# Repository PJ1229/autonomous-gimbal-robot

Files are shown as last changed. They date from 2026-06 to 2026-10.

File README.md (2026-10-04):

# auto-gimbal
project by PJ Kim

## to-do:
- [ ] order parts
- [ ] set up ros2 on raspi

## dev rules:
1. no ai agents in this repo (ai for research & planning only)
2. this repo is the source of truth for the entire project

## external links
- [devlog](docs/devlog.md)
- [part list](hardware/bom/part-list.md)
- [chassis dimensions](hardware/bom/chassis-dimensions.md)
- [base layout (rough CAD)](hardware/cad/base-layout.md)

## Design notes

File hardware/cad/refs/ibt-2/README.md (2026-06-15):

# IBT-2 (BTS7960) motor driver reference model

High-power H-bridge driver (ordered ×3). Exported for electronics bay layout in Inventor.

| File | Format | Notes |
|---|---|---|
| `ibt-2.step` | STEP | **Module only** — use for chassis footprint (50×50×43 mm) |
| `ibt-2-wiring.step` | STEP | Module + signal wiring + mounting screws |

Board dims: 50 × 50 × 43 mm · ~66 g · 6–27 V · one per drive motor.

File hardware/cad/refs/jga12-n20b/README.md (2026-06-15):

# JGA12-N20B encoder motor reference model

Magnetic encoder N20 gear motor (12 V, ordered ×4). Exported for motor mount layout in Inventor.

| File | Format | Notes |
|---|---|---|
| `jga12-n20b.sat` | ACIS SAT | **Preferred for Inventor** — solid B-rep import |
| `jga12-n20b.stl` | STL | Mesh fallback / quick preview |

Dimensional drawing: [`part-photos/drive/motor.jpeg`](../../bom/part-photos/drive/motor.jpeg)

Key dims: 40 mm overall length, φ3 mm D-shaft, face 12×10 mm, bracket tabs 17.6 mm apart.

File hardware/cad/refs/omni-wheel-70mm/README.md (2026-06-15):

# 70 mm omni wheel reference model

MiJunHD 70 mm omni wheel with coupling (ordered ×3). For wheel clearance and axle layout in Inventor.

## Inventor import

| File | Inventor? | Use |
|---|---|-----|
| `omni-wheel-70mm.step` | **Yes** (best) | Export from `Omni_4_70.SLDASM` → full solid assembly |
| `omni-wheel-70mm-carrier.stl` | Yes (mesh) | Hub/carrier only — rough clearance check |
| `omni-wheel-70mm-roller.stl` | Yes (mesh) | Single roller — place 4× manually if needed |
| `Omni_4_70.SLDASM` | **No** | SolidWorks only — edit source, then export STEP |
| `*.SLDPRT` | **No** | SolidWorks only (gitignored) |

**Recommended workflow**
1. Open `Omni_4_70.SLDASM` in SolidWorks
2. **File → Save As → STEP** → save as `omni-wheel-70mm.step` in this folder
3. In Inventor: open `base.ipt` → **Place Component** → select `omni-wheel-70mm.step`

STL imports are triangle meshes — no precise mates. Use only until STEP is exported.

## Specs

**Dims:** φ70 × 35.4 mm wide · **3 mm** coupling bore · see [`part-photos/drive/omni-wheel.jpg`](../../bom/part-photos/drive/omni-wheel.jpg)

SolidWorks source files stay local (gitignored). Commit `omni-wheel-70mm.step` once exported.

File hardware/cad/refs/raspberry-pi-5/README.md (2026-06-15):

# Raspberry Pi 5 reference models

Exported for chassis layout in Inventor.

| File | Format | Notes |
|---|---|---|
| `raspberry-pi-5-cooler.step` | STEP | **Use this** — Pi 5 + stock active cooler assembly |
| `raspberry-pi-5.step` | STEP | Board only (no cooler) |
| `raspberry-pi-5.stl` | STL | Board only mesh — quick preview |

Board: 85×56 mm · Cooler adds **+13.7 mm** above CPU side · M2.5 standoffs on 58×49 mm pattern.

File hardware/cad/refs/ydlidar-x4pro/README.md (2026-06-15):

# YDLIDAR X4PRO reference model

360° 2D LiDAR (in hand ×1). Exported for top-deck mount layout in Inventor.

| File | Format | Notes |
|---|---|---|
| `ydlidar-x4pro.step` | STEP | Import into `base.ipt` assembly |

**Dims:** 110.6 × 71.1 × 52.3 mm · [datasheet](https://static.generation-robots.com/media/YDLIDARX4PRODatasheet.pdf) · [Amazon](https://www.amazon.com/EC-Buying-Triangular-Raspberry-Navigation/dp/B0D3CWVSZX)

Mount centered on top deck with ≥60 mm clear radius at scan height.

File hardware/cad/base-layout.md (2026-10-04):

# Base Layout — Rough CAD Blocks

Simplified footprints for blocking out `base.ipt`. All **mm**.

**Base plate:** 3 mm plywood · design on 305 × 305 stock · axle height **35** (wheel radius)

Last updated: 2026-07-08

---

## On the base (block these first)

| Part | Qty | Footprint (L × W) | Height ↑ | Radius / sweep | Notes |
|---|-----|---|---|---|---|
| 70 mm omni wheel | 3 | **φ70** (R35) | axle at **35** from ground | **R38** min per corner | 3 mm shaft · [CAD](refs/omni-wheel-70mm/) |
| N20 motor + bracket | 3 | **30 × 45** mount plate | **18** body | **45** along axle | φ3 shaft · [CAD](refs/jga12-n20b/) |
| IBT-2 driver | 3 | **50 × 50** | **43** | — | one per wheel · [CAD](refs/ibt-2/) |
| Pi 5 + cooler | 1 | **85 × 56** | **32** | — | M2.5 standoffs · [CAD](refs/raspberry-pi-5/) |
| LiPo 2200 mAh | 1 | **110 × 40** | **28** | — | add 20 for T-plug end |
| Buck converter | 1 | **45 × 20** | **10** | — | ⚠️ measure yours |
| YDLIDAR X4PRO | 1 | **111 × 71** | **53** | **R60** clear at scan height | center top · [CAD](refs/ydlidar-x4pro/) |
| Pi camera | 1 | **25 × 24** | **12** | — | on gimbal post · ⚠️ confirm model |
| MG996R servo | 2 | **41 × 20** | **43** | — | pan + tilt · planned |

---

## By layer (top → bottom)

### Top deck (above main plate)
| Part | Block size | Stack height |
|---|---|---|
| LiDAR | 111 × 71 | **53** |
| Gimbal post + camera | 50 × 50 base | **80–120** (estimate) |

### Main plate (electronics)
| Part | Block size | Stack height |
|---|---|---|
| Pi 5 + cooler | 85 × 56 | **32** |
| 3× IBT-2 (side by side) | **150 × 50** total | **43** |
| Battery | 110 × 40 | **28** |
| Buck converter | 45 × 20 | **10** |

### Below / at plate edge (drive)
| Part | Block size | From ground |
|---|---|---|
| Wheel (per corner) | **φ70** | center at **35** |
| Motor mount | 30 × 45 | plate ~**20–25** above ground |

---

## Minimum zones (cutouts / keep-clear)

| Zone | Size | Why |
|---|---|-----|
| Wheel corner ×3 | **φ75** each | roller overhang |
| LiDAR scan | **φ120** centered | 360° unobstructed |
| Pi USB / GPIO side | +**15** margin | cables |
| Wheel triangle | **120–150** between axle centers | 3-wheel omni starting point |

---

## Quick cylinders (Inventor primitives)

Use these if you aren't importing refs yet:

```
Wheel:     R35, thickness 35
Motor:     12 × 18 cross-section, length 40 along axle
Driver:    50 × 50 × 43 box
Pi stack:  85 × 56 × 32 box
LiDAR:     111 × 71 × 53 box
Battery:   110 × 40 × 28 box
Camera:    25 × 24 × 12 box
```

---

## CAD refs

| Part | Import file |
|---|---|
| Pi 5 + cooler | `refs/raspberry-pi-5/raspberry-pi-5-cooler.step` |
| Motor | `refs/jga12-n20b/jga12-n20b.sat` |
| LiDAR | `refs/ydlidar-x4pro/ydlidar-x4pro.step` |
| Driver | `refs/ibt-2/ibt-2.step` |
| Omni wheel | export `refs/omni-wheel-70mm/omni-wheel-70mm.step` from SW |

Full detail: [chassis-dimensions.md](../bom/chassis-dimensions.md)

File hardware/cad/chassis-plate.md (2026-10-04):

# Chassis plate cut files

Same hexagon as Inventor `chassis.ipt` / `chassis.dwg`, scaled up and cleaned for laser cut.

| File | Use |
|---|-----|
| `chassis-plate.dxf` | **Preferred** for most lasers |
| `chassis-plate.dwg` | AutoCAD / Inventor |
| `chassis-plate.svg` | Preview / Inkscape |
| `chassis.dwg` | Original Inventor export (small + sheet border) — keep as reference |

## Size

| | Original | Cut file |
|--|---|---|
| Bbox | 120 × 104 mm | **280 × 242.5 mm** |
| Scale | 1× | **2.33×** |
| Units | inches (on ANSI sheet) | **mm** |
| Border / title block | included | **removed** |

Fits **305 × 305 × 3 mm** birch plywood (~12 mm margin on the long side).

## Notes

- Outline only — no mounting holes yet (add after motor/Pi/LiDAR placement)
- Layer `CUT` in the DXF
- Origin ≈ plate centroid

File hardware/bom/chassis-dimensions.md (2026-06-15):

# Chassis Dimensions Reference

Dimensions for CAD / laser-cut layout. All values in **mm** unless noted.

**Sources:** product photos in `part-photos/`, order records, manufacturer datasheets. Items marked ⚠️ need physical measurement or model confirmation.

Last updated: 2026-06-15

---

## Quick Reference

| Part | L × W × H | Weight | Mount / shaft | Chassis notes |
|---|---|---|---|---|
| JGA12-N20B motor | 40 × 12 × 18 | — | M1.6×2 (9 mm spacing), **φ3 mm D-shaft** | CAD ref: `hardware/cad/refs/jga12-n20b/` |
| Motor bracket | 25.4 × 14.4 × 9.85 | — | φ2.25 mm holes, 17.6 mm spacing | U-clamp over gearbox face |
| 70 mm omni wheel | **φ70** × 35.4 wide | 83 g | **3 mm** clamp coupling | CAD ref: `hardware/cad/refs/omni-wheel-70mm/` |
| 3 mm hex coupling | 12 edge-to-edge | 8.3 g | Clamps onto motor shaft | Matches N20 shaft |
| BTS7960 (IBT-2) driver ×3 | 50 × 50 × 43 | ~66 g | 4× corner holes (M3 typical) | CAD ref: `hardware/cad/refs/ibt-2/` |
| Raspberry Pi 5 + cooler | 85 × 56 × ~32 | 45 g | 4× M2.5 holes (58 × 49 mm pattern) | CAD ref: `raspberry-pi-5-cooler.step` |
| Pi 5 active cooler | 63.5 × 42.5 × 13.7 | — | Included in cooler assembly | +13.7 mm above board |
| Pi Camera Module ⚠️ | 25 × 24 × ~11.5 | — | 2× M2 holes (CM2/CM3 PCB) | Confirm which module you have |
| YDLIDAR X4PRO | **110.6 × 71.1 × 52.3** | — | Base plate, center mount | CAD ref: `hardware/cad/refs/ydlidar-x4pro/` |
| Zeee 3S LiPo 2200 mAh | 102 × 34 × 23 | 170 g | Velcro / strap bay | T-plug + JST-XH stick out ~15 mm |
| Buck converter (LY-1658) | ~45 × 20 × 10 ⚠️ | — | 2× tab screw holes | Measure on arrival; not on Amazon listing |
| MG996R servo ×2 (planned) | 40.7 × 19.7 × 42.9 | 55 g | M3, 40 × 49 mm hole pattern | Gimbal pan + tilt |
| Birch plywood sheet | 305 × 305 × 3 | — | — | Stock material |

---

## Drive Train

### JGA12-N20B encoder motor (ordered ×4)

CAD reference: [`hardware/cad/refs/jga12-n20b/`](../cad/refs/jga12-n20b/) (`jga12-n20b.sat`)

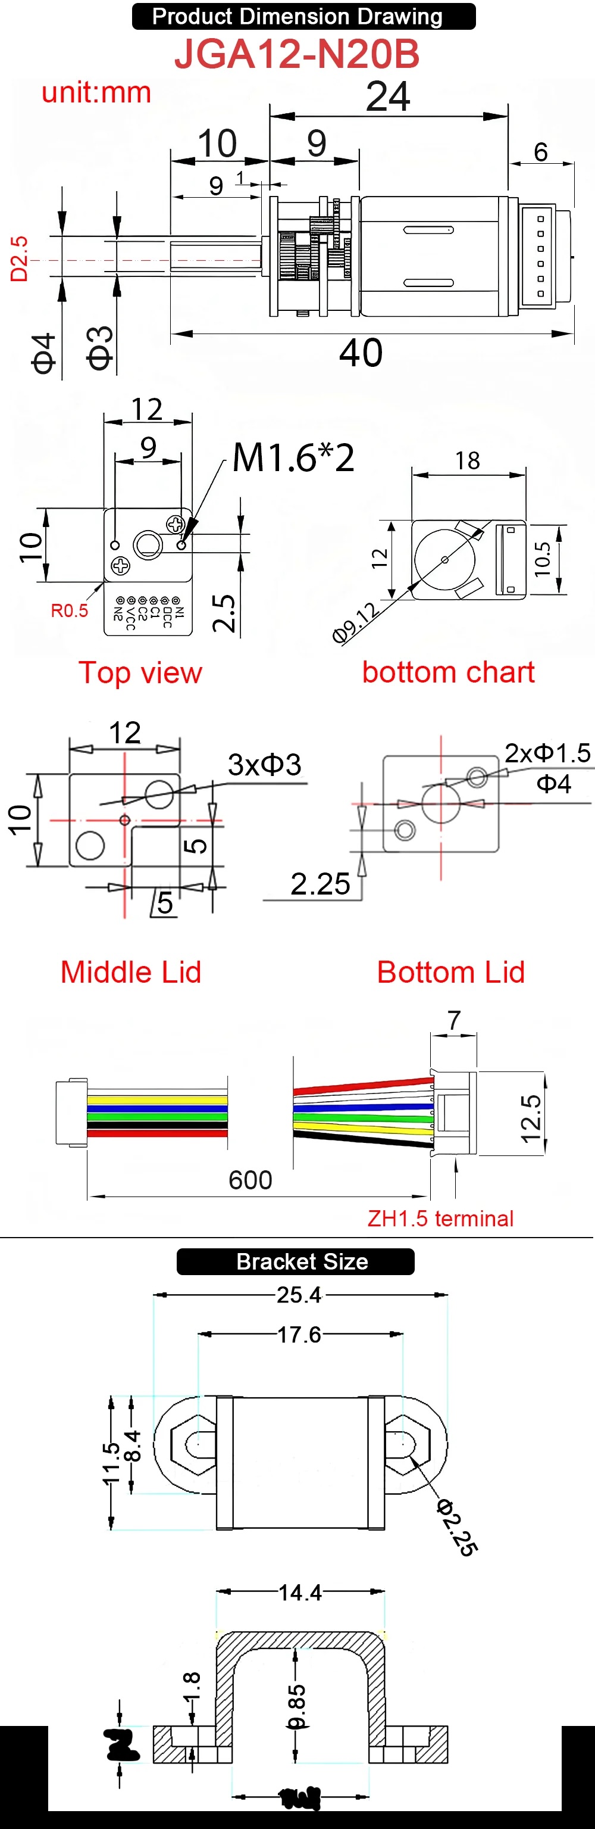
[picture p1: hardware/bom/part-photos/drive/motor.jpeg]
Motor drawing


| Dimension | Value |
|---|---|
| Overall length (rear to shaft tip) | **40** |
| Motor body length | 24 |
| Gearbox length | 9 |
| Rear overhang | 6 |
| Face plate (mounting face) | **12 × 10** |
| Motor body cross-section | 12 × 18 (φ9.12 motor can) |
| Output shaft | **φ3 mm**, **10 mm** long, D-flat **2.5 mm** deep × 9 mm |
| Shaft shoulder | φ4 mm at gearbox |
| Mounting holes (face) | **M1.6×2**, **9 mm** center-to-center |
| Encoder connector | 6-pin ZH1.5, 600 mm cable |

**Included bracket**

| Dimension | Value |
|---|---|
| Overall width (tab to tab) | 25.4 |
| Mount hole spacing | 17.6 |
| Mount hole diameter | φ2.25 |
| Bracket width (cross-section) | 14.4 |
| Internal height | 9.85 |
| Base thickness | 1.8 |
| Bottom opening | 10.1 |

**CAD tip:** Motor mounts to chassis through bracket tabs, not directly through the M1.6 face holes. Leave **≥45 mm** clearance along motor axis (motor body + coupling + wheel hub).

---

### 70 mm omni wheel + 3 mm coupling (ordered ×3)

CAD reference: [`hardware/cad/refs/omni-wheel-70mm/`](../cad/refs/omni-wheel-70mm/) — export `omni-wheel-70mm.step` from `Omni_4_70.SLDASM` for Inventor; STLs work as mesh fallback

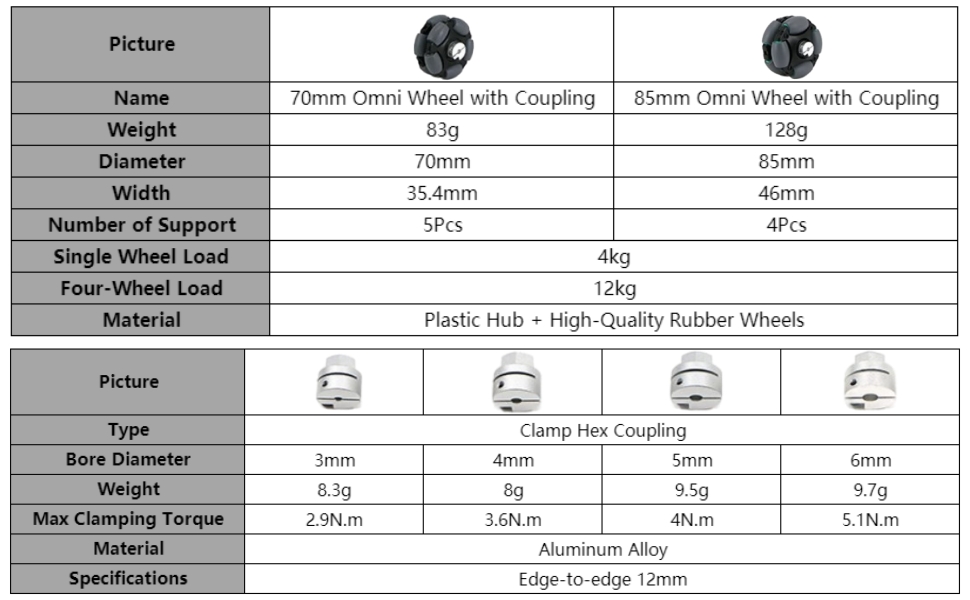
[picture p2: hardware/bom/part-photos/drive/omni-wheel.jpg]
Wheel specs


| Dimension | Value |
|---|---|
| Wheel diameter | **70** |
| Wheel width (tread) | **35.4** |
| Roller supports | 5 |
| Load (single / 4-wheel) | 4 kg / 12 kg |
| Coupling type | Clamp hex, aluminum |
| Coupling bore | **3 mm** (matches N20 shaft) |
| Coupling size | 12 mm edge-to-edge |
| Max clamp torque | 2.9 N·m |

**CAD tip:** Axle height from ground ≈ **35 mm** (half wheel diameter). Wheel width extends **±17.7 mm** from axle centerline. Leave **≥75 mm** diameter sweep per wheel corner (roller overhang).

> **Note:** `part-list.md` Amazon link shows a 5 mm coupling variant — your order (`orders.csv`) is **3 mm**, which matches the motor shaft. Use 3 mm in CAD.

---

### BTS7960 / IBT-2 motor driver (ordered ×3)

CAD reference: [`hardware/cad/refs/ibt-2/`](../cad/refs/ibt-2/) (`ibt-2.step`)

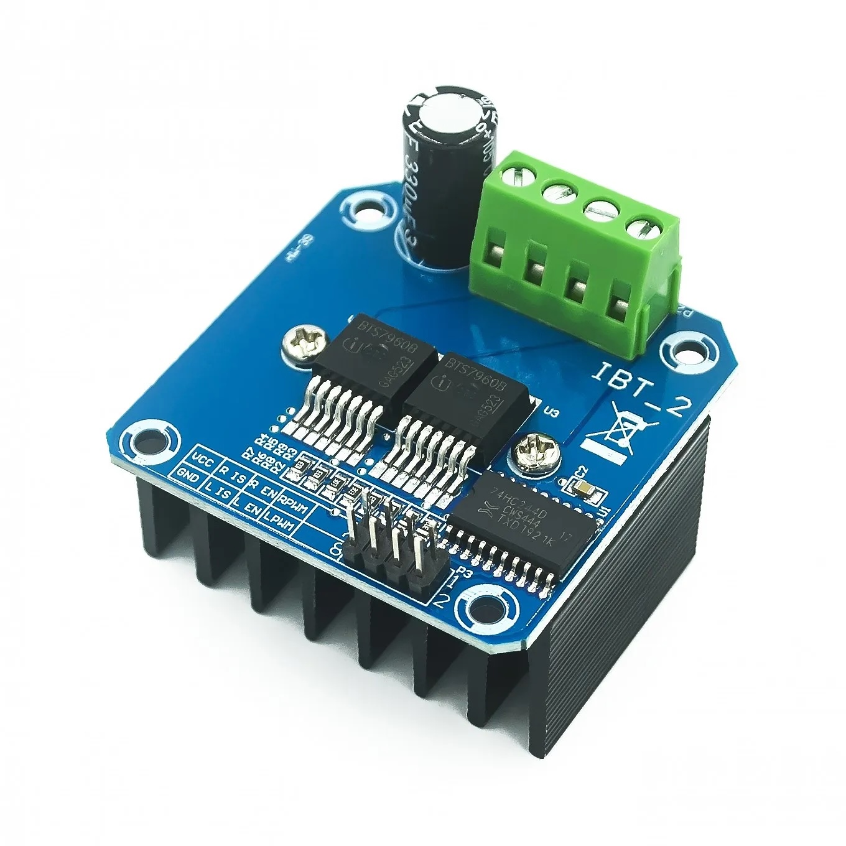
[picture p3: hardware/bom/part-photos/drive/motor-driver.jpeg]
Driver board


| Dimension | Value |
|---|---|
| Board (L × W × H) | **50 × 50 × 43** (incl. heatsink) |
| Weight | ~66 g |
| Mounting | 4× corner holes (typically M3) |
| Power input | 6–27 V (B+/B− screw terminal) |
| Motor output | M+/M− screw terminal |
| Logic header | 8-pin 2.54 mm (RPWM, LPWM, R_EN, L_EN, R_IS, L_IS, VCC, GND) |

**CAD tip:** Stack 3 drivers side-by-side = **≥150 mm** width if laid flat. Mount vertically on standoffs to save footprint. Keep heatsink fins unobstructed.

---

## Compute + Sensors

### Raspberry Pi 5 + active cooler (in hand)

CAD reference: [`hardware/cad/refs/raspberry-pi-5/`](../cad/refs/raspberry-pi-5/) (`raspberry-pi-5-cooler.step`)

| Dimension | Value |
|---|---|
| Board (L × W) | **85 × 56** |
| Board thickness | ~1.6 mm PCB; tallest components ~17 mm |
| Mounting holes | 4× **M2.5**; hole pattern **58 × 49 mm** (corner to corner) |
| Hole diameter | ~2.7–3.0 mm |
| Active cooler footprint | **63.5 × 42.5** |
| Active cooler height above board | **+13.7** |
| USB-C power | Right side — leave **10 mm** cable bend radius |
| GPIO header | 40-pin, 2.54 mm pitch along board edge |

**CAD tip:** Total stack height with cooler ≈ **30–32 mm**. Use **M2.5 standoffs 11–15 mm** to allow airflow under board. Keep camera ribbon route (between CSI connector and board edge) unblocked.

---

### YDLIDAR X4PRO (in hand ×1)

CAD reference: [`hardware/cad/refs/ydlidar-x4pro/`](../cad/refs/ydlidar-x4pro/) (`ydlidar-x4pro.step`)

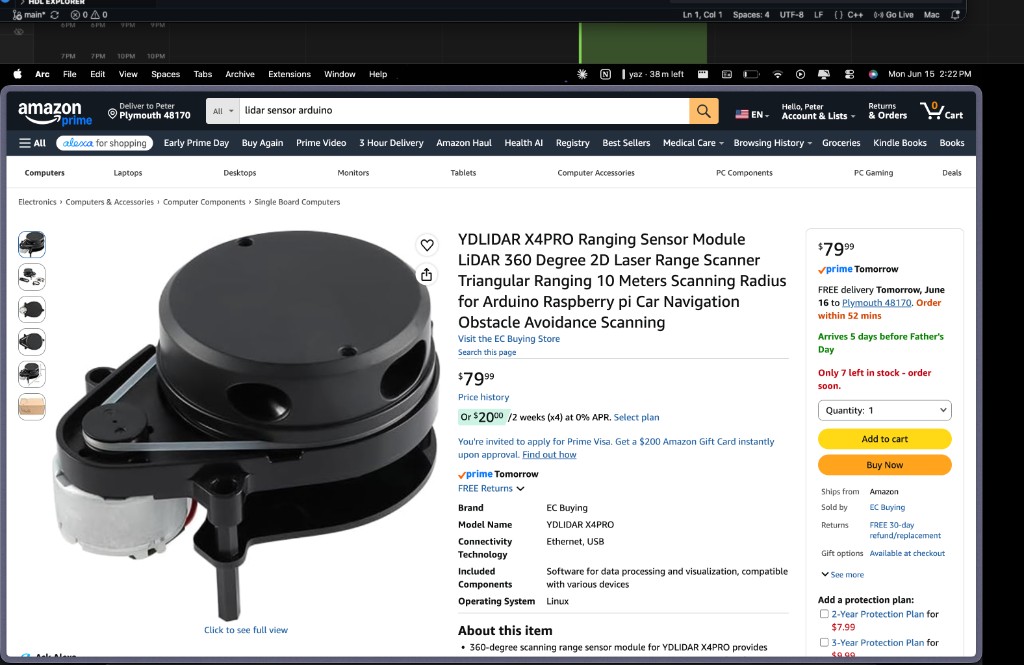
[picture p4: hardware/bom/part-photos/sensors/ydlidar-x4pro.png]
YDLIDAR X4PRO


[Amazon listing](https://www.amazon.com/EC-Buying-Triangular-Raspberry-Navigation/dp/B0D3CWVSZX) · [YDLIDAR product page](https://www.ydlidar.com/product/ydlidar-x4-pro) · [Datasheet (PDF)](https://static.generation-robots.com/media/YDLIDARX4PRODatasheet.pdf)

| Dimension | Value |
|---|---|
| Body (L × W × H) | **110.6 × 71.1 × 52.3** |
| Scan angle | **360°** |
| Range | **0.12–10 m** (indoor, 80% reflectivity) |
| Ranging frequency | 5000 Hz |
| Scan frequency | 6–12 Hz (PWM speed control) |
| Angle resolution | 0.43° @ 6 Hz – 0.86° @ 12 Hz |
| Accuracy | ±2 cm (≤1 m); ±3.5% (1–6 m) |
| Supply voltage | **4.8–5.2 V** (use buck converter 5 V rail) |
| Working current | 330 mA typical; 800–1000 mA startup |
| Interface | **UART** (3.3 V logic) |
| ROS2 driver | `ydlidar_ros` / `ydlidar_ros2_driver` |

**CAD tip:** Mount **centered on top deck**. Keep **≥60 mm radius** clear of obstructions at scan plane height. Budget **≥53 mm** stack height above deck. Power from Pi 5 USB or dedicated 5 V rail — not 3.3 V. Route UART to Pi GPIO (3.3 V level).

**Mounting:** Black base plate with side motor + belt drive to rotating head. Use manufacturer mechanical drawing for exact hole positions ([X4PRO drawing PDF](https://aifitlab.com/products/ydlidar-x4-pro-lidar)).

---

### Raspberry Pi Camera Module (in hand ×2) ⚠️

Model not confirmed. Dimensions below are for **Camera Module 2 / 3** (most common Pi ribbon cameras).

| Dimension | Value |
|---|---|
| PCB (L × W × H) | **25 × 24 × 11.5** (CM3 standard; Wide = 12.4 mm H) |
| Mounting holes | 2× **M2**, same positions as CM2 |
| Ribbon connector | 15-pin FPC, 200 mm cable typical |
| Lens protrusion | ~2–3 mm above PCB |

**Action:** Check label on module or ribbon — note model in `inventory.md` after confirming.

---

## Power

### Zeee 3S LiPo 2200 mAh (in hand ×2)

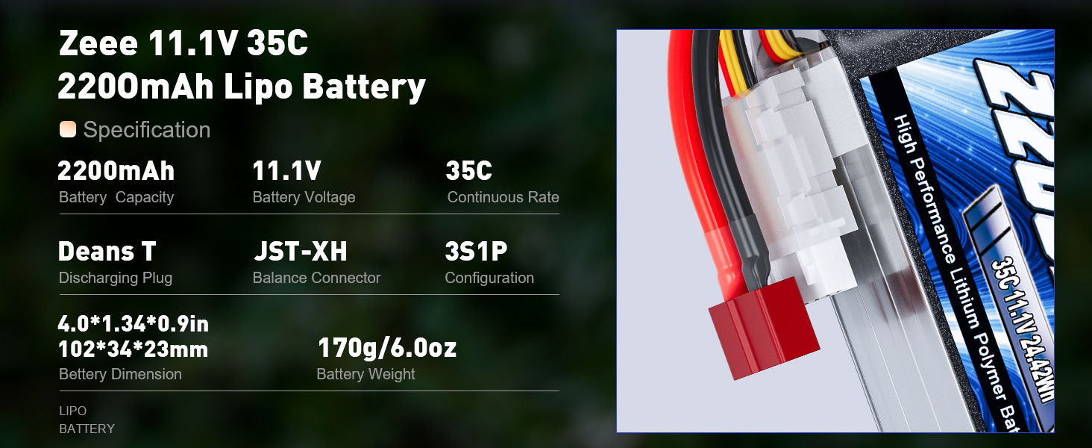
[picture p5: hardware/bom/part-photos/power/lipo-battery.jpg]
Battery specs


| Dimension | Value |
|---|---|
| Pack (L × W × H) | **102 × 34 × 23** |
| Weight | 170 g |
| Connector (power) | Deans **T-plug** (add ~20 mm to length) |
| Connector (balance) | JST-XH 4-pin |
| Voltage | 11.1 V (3S) |

**CAD tip:** Battery bay ≥ **110 × 40 × 28 mm** with foam strap. Route T-plug toward buck converter; keep away from Pi. Add **XT60 or T-to-screw-terminal adapter** if hard-wiring.

---

### DC 12 V → 5 V USB-C buck converter (in hand)

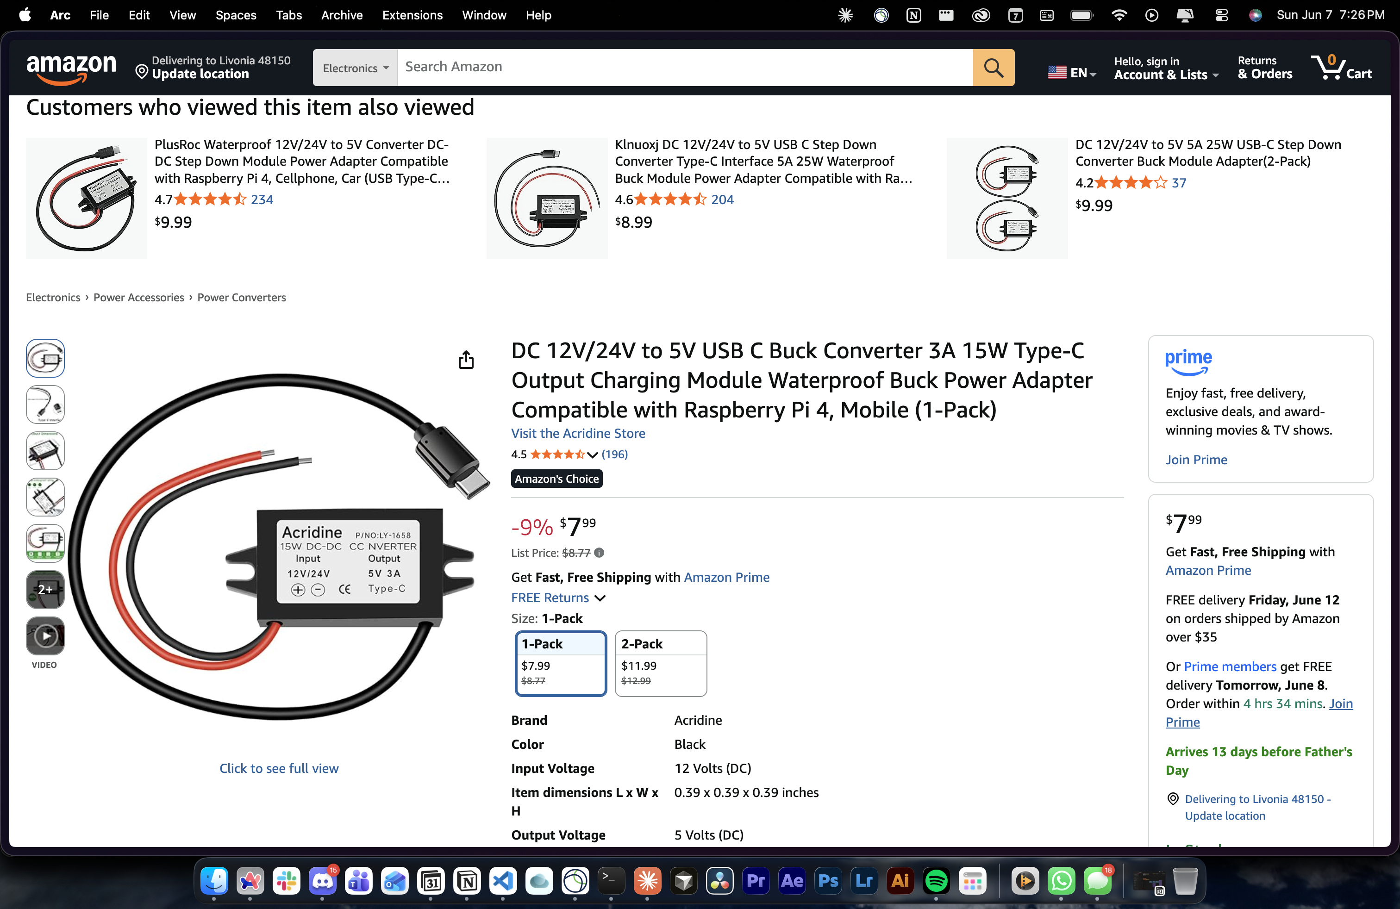
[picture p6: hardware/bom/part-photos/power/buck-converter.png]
Buck converter


| Dimension | Value |
|---|---|
| Model | Acridina LY-1658 (label) / P/N L116666 (inventory) |
| Input | 12–24 V (red/black leads) |
| Output | 5 V 3A USB-C |
| Enclosure | Potted, 2× mounting tabs with screw holes |
| Size | **⚠️ measure on arrival** — Amazon listing is wrong (~10 mm cube) |

**CAD tip:** Mount near battery with input wires short. USB-C cable to Pi 5 power port — leave service loop.

---

## Gimbal (planned — Week 5+)

### MG996R servo ×2

| Dimension | Value |
|---|---|
| Body (L × W × H) | **40.7 × 19.7 × 42.9** |
| Weight | 55 g |
| Mount hole spacing | **40 mm** (horizontal) × **49 mm** (vertical) |
| Mount holes | φ3.0 → **M3** screws |
| Output shaft spline | ~25T, ~6 mm diameter |
| Shaft protrusion | ~3–4 mm above body |

**CAD tip:** Pan servo flat on deck; tilt servo on horn bracket. Clearance hole for spline ≥ **7 mm**. CF tube mount: **φ20 mm** tube, ~300 mm length (planned).

---

## Materials

### Birch plywood (ordered)

| Dimension | Value |
|---|---|
| Sheet size | **305 × 305** (12" × 12") |
| Thickness | **3** (1/8") |
| Pack qty | 12 sheets |

---

## Suggested Chassis Layout (3-wheel omni)

Based on `docs/sketches/initial-design.jpg`:

```
                    [ LiDAR — center, top deck ]
                           |
              [ Pi 5 + cooler — rear/center ]
                           |
         [ Camera + gimbal post — front center ]
                           |
    [ Battery ]  [ 3× BTS7960 ]  [ Buck conv. ]
                           |
              _____________|_____________
             /        chassis plate       \
        [wheel]                        [wheel]
                    [wheel]
```

### Minimum deck sizes (starting point)

| Zone | Min footprint | Min height above deck |
|---|---|---|
| Wheel corners (3×) | 75 mm dia. each at triangle vertices | Axle at 35 mm from ground |
| Motor + bracket per corner | 30 × 45 mm mount plate | — |
| Electronics bay | 120 × 80 mm | 45 mm (drivers + wiring) |
| Pi stack | 90 × 60 mm | 35 mm |
| Battery bay | 110 × 40 mm | 28 mm |
| LiDAR pad (center) | **115 × 75 mm** | **53 mm** above deck |
| Gimbal post (front) | 50 × 50 mm base | 80–120 mm above deck |

### 3-wheel omni wheelbase

For a triangular layout with 70 mm wheels, a **120–150 mm** spacing between wheel centers is a reasonable starting point for a small indoor robot. Tune in CAD so rollers don't collide with chassis edge at max steering angle.

---

## Measure When Parts Arrive

- [ ] Pi Camera — confirm CM1 / CM2 / CM3 / HQ
- [ ] Buck converter — L × W × H and tab hole spacing
- [ ] BTS7960 — confirm mount hole spacing on physical board (CAD ref available)
- [ ] N20 motor — verify bracket included in AliExpress shipment
- [ ] Omni wheel coupling — confirm 3 mm bore on physical part

---

## Related Files

- [part-list.md](part-list.md)
- [inventory.md](inventory.md)
- [orders.csv](orders.csv)
- [initial design sketch](../../docs/sketches/initial-design.jpg)

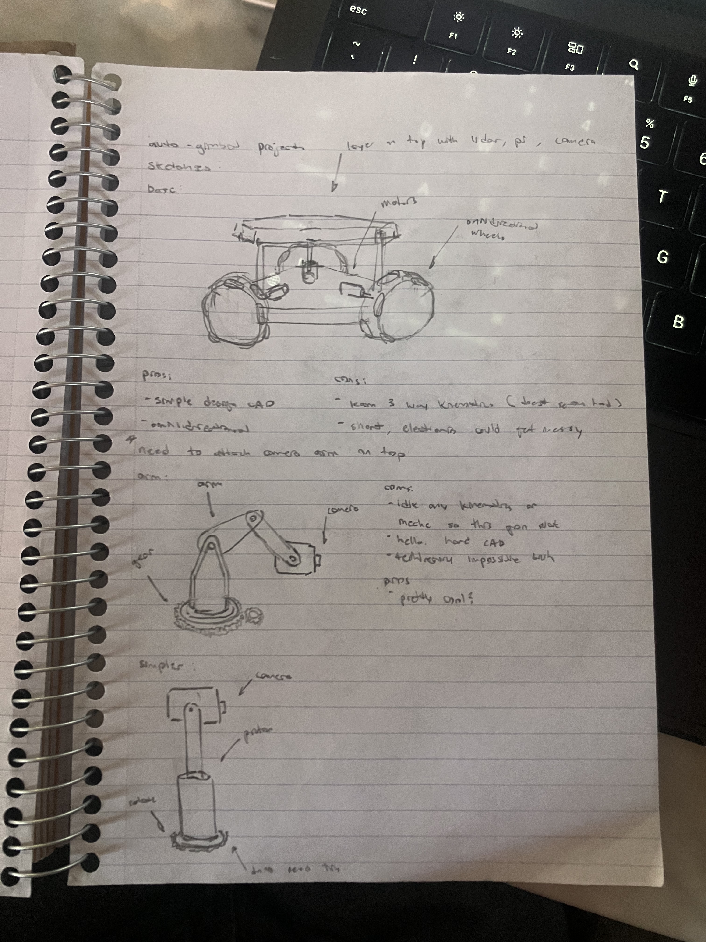
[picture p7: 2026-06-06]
docs/sketches/initial-design.jpg

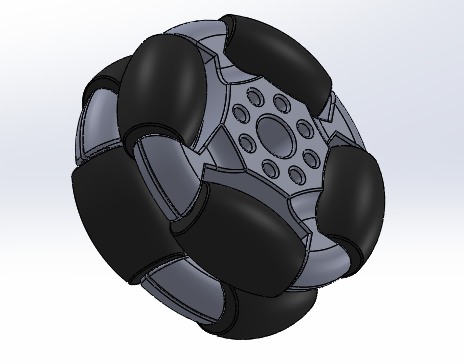
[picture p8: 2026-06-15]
hardware/cad/refs/omni-wheel-70mm/omni-wheel-70mm.png

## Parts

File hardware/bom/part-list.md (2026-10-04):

# part list (goal >$300)
## drive
- [X] [3x 70mm omni wheel rubber id 5mm coupling](https://www.amazon.com/MiJunHD-Plastic-Omni-Directional-Movement-Coupling/dp/B0FRRMVX75/132-6057551-6935601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) ([CAD](../cad/refs/omni-wheel-70mm/))
- [X] [4x N20 gear motor 12V 100rpm](https://www.aliexpress.us/item/3256806026901950.html?src=google&gatewayAdapt=glo2usa) ([CAD](../cad/refs/jga12-n20b/))
- [X] [3x bts7960 motor driver 5.5-27V](https://www.aliexpress.us/item/2251801812908062.html?src=google&gatewayAdapt=glo2usa#nav-specification) ([CAD](../cad/refs/ibt-2/))
## power
- [X] [3S LiPo 2200mAh](part-photos/power/lipo-battery.jpg)
- [X] [Balance charger](part-photos/power/balance-charger.png)
- [X] [5V USB-C buck converter](part-photos/power/buck-converter.png)
## compute
- [X] [raspberry pi 5 wifi + cooler](inventory.md) ([CAD](../cad/refs/raspberry-pi-5/))
- [X] [32gb microSD card](inventory.md)
## sensors
- [X] [YDLIDAR X4PRO](https://www.amazon.com/EC-Buying-Triangular-Raspberry-Navigation/dp/B0D3CWVSZX) ([photo](part-photos/sensors/ydlidar-x4pro.png), [CAD](../cad/refs/ydlidar-x4pro/))
## wiring/hardware
- [X] [M2/M3 540pcs bolt kit](part-photos/tools/m2m3-bolt-kit.png)
- [X] [22AWG silicone wire + heat shrink](inventory.md)
- [X] [Dupont jumper wire kit](inventory.md)
## materials
- [X] [12x12 birch plywood 1/8" 12-pack](https://www.amazon.com/dp/B0DLNJRP9L?th=1)

See [chassis-dimensions.md](chassis-dimensions.md) for part sizes and mount specs for CAD.
See [base-layout.md](../cad/base-layout.md) for simplified blocking sizes on the base plate.
## arm/gimbal
- [ ] 2x MG996R servos — order Week 5
- [ ] 20mm carbon fiber tube ~300mm — order Week 5

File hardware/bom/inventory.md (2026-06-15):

# Fred Film Bot — Hardware Inventory

Last updated: 2026-06-15

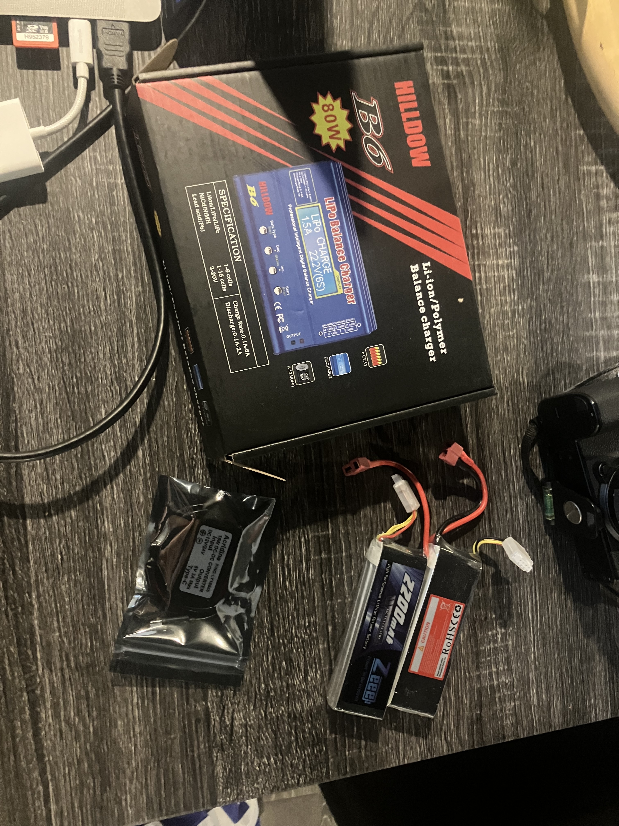
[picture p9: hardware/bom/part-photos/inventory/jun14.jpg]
Jun 14 power intake


## Compute
| Item | Qty | Notes |
|---|-----|---|
| Raspberry Pi 5 + active cooler | 1 | Primary robot brain |
| Raspberry Pi 4 | 1 | Available for testing/development |
| Arduino R4 WiFi | 2 | Available for peripheral control |

## Cameras
| Item | Qty | Notes |
|---|-----|---|
| Raspberry Pi Camera Module | 2 | Specs unknown — check ribbon connector type |

## Sensors
| Item | Qty | Notes |
|---|-----|---|
| YDLIDAR X4PRO | 1 | 110.6×71.1×52.3 mm; 0.12–10 m; 360°; UART @ 5 V; [Amazon](https://www.amazon.com/EC-Buying-Triangular-Raspberry-Navigation/dp/B0D3CWVSZX) · [datasheet](https://static.generation-robots.com/media/YDLIDARX4PRODatasheet.pdf) |

## Motor Control
| Item | Qty | Notes |
|---|-----|---|
| L298N motor driver | 3 | Max 10V motor supply — not for 12V LiPo use |
| TT gear motor dual shaft 3-6V + bracket + wheels | 4 | Good for early prototyping |

## Power
| Item | Qty | Notes |
|---|-----|---|
| HILLDOW B6 80W balance charger + power supply | 1 | Li-ion/LiPo/LiFe 1–6S; includes XT60, JST, T connectors |
| Zeee 3S LiPo 2200mAh 11.1V 35C | 2 | T connector (Deans) |
| DC 12V→5V USB-C buck converter 3A 15W | 1 | Acridina L116666 — powers Pi 5 from LiPo |
| 9V battery | 2 | |
| 9V battery → DC barrel jack adapter | 4 | |
| On/off switch (wired) | 9 | |

## Prototyping
| Item | Qty | Notes |
|---|-----|---|
| 400-point breadboard | 8 | |
| 830-point breadboard | 1 | |
| MicroSD 32GB | 1 | Use for ROS2 — upgrade to 64GB if storage runs low |
| Assorted wires + transistors | — | Qty unspecified |
| 9–12V LED 5mm wired | ~30 | |

## Tools
| Item | Qty | Notes |
|---|-----|---|
| Soldering kit | 1 | |
| Wire cutters | 1 | |
| Box cutter | 1 | |
| Wood glue | 1 | |
| Masking tape | 1 | |

## Materials
| Item | Qty | Notes |
|---|-----|---|
| Wooden sticks | — | Qty unspecified |
| Origami paper 15×15cm | ~40 | |

## On Order
| Item | Qty | Supplier | Order # | ETA | Status |
|---|-----|---|---|-----|---|
| JGA12-N20B encoder motor 200RPM 12V | 4 | AliExpress | 8212329737371495 | Jun 16–24 | ordered |
| 70mm omni wheel + 3mm coupling | 3 | Amazon | 113-8814706-5927456 | Jun 22–Jul 2 | ordered |
| BTS7960 motor driver | 3 | Walmart | 2000149-49464347 | Jun 22–Jul 2 | ordered |
| Ninekong birch plywood 12×12 1/8″ 12-pack | 1 | Amazon | 112-0041733-2565822 | Jun 15 | ordered |

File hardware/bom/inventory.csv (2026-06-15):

category | item | quantity | unit | status | supplier | order_number | eta_start | eta_end | notes
compute | Raspberry Pi 5 + active cooler | 1 | unit | in hand |  |  |  |  | Primary robot brain
compute | Raspberry Pi 4 | 1 | unit | in hand |  |  |  |  | Available for testing
compute | Arduino R4 WiFi | 2 | unit | in hand |  |  |  |  | Available for peripheral control
cameras | Raspberry Pi Camera Module | 2 | unit | in hand |  |  |  |  | Specs unknown — check ribbon connector
sensors | YDLIDAR X4PRO | 1 | unit | in hand |  |  |  |  | 110.6x71.1x52.3mm; 0.12-10m; 360deg; UART 5V; ydlidar_ros2_driver
motor_control | L298N motor driver | 3 | unit | in hand |  |  |  |  | Max 10V — not for 12V LiPo use
motor_control | TT gear motor dual shaft 3-6V + bracket + wheels | 4 | unit | in hand |  |  |  |  | Good for early prototyping
power | HILLDOW B6 80W balance charger + power supply | 1 | unit | in hand |  |  |  |  | Li-ion/LiPo/LiFe 1-6S; includes XT60 JST T connectors
power | Zeee 3S LiPo 2200mAh 11.1V 35C | 2 | unit | in hand |  |  |  |  | T connector (Deans)
power | DC 12V to 5V USB-C buck converter 3A 15W | 1 | unit | in hand |  |  |  |  | Acridina L116666 - powers Pi 5 from LiPo
power | 9V battery | 2 | unit | in hand
power | 9V battery to DC barrel jack adapter | 4 | unit | in hand
power | On/off switch wired | 9 | unit | in hand
prototyping | 400-point breadboard | 8 | unit | in hand
prototyping | 830-point breadboard | 1 | unit | in hand
prototyping | MicroSD 32GB | 1 | unit | in hand |  |  |  |  | Upgrade to 64GB if storage runs low
prototyping | Assorted wires + transistors | 0 | lot | in hand |  |  |  |  | Qty unspecified
prototyping | 9-12V LED 5mm wired | 30 | unit | in hand |  |  |  |  | Approximate qty
tools | Soldering kit | 1 | unit | in hand
tools | Wire cutters | 1 | unit | in hand
tools | Box cutter | 1 | unit | in hand
tools | Wood glue | 1 | unit | in hand
tools | Masking tape | 1 | unit | in hand
materials | Wooden sticks | 0 | lot | in hand |  |  |  |  | Qty unspecified
materials | Origami paper 15x15cm | 40 | sheet | in hand |  |  |  |  | Approximate qty
on_order | JGA12-N20B encoder motor 200RPM 12V | 4 | unit | ordered | AliExpress | 8212329737371495 | 2026-06-16 | 2026-06-24
on_order | 70mm omni wheel + 3mm coupling | 3 | unit | ordered | Amazon | 113-8814706-5927456 | 2026-06-22 | 2026-07-02
on_order | BTS7960 motor driver | 3 | unit | ordered | Walmart | 2000149-49464347 | 2026-06-22 | 2026-07-02
on_order | Ninekong birch plywood 12x12 1/8 inch 12-pack | 1 | pack | ordered | Amazon | 112-0041733-2565822 | 2026-06-15 | 2026-06-15 | 12 sheets 3mm birch for laser cutting and chassis prototyping

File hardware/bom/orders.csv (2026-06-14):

date | item | quantity | unit_price | total | supplier | order_number | eta_start | eta_end | status | notes
2026-06-06 | BTS7960 motor driver | 3 | 11.05 | 33.14 | Walmart | 2000149-49464347 | 2026-06-22 | 2026-07-02 | ordered | one per motor - 12V compatible
2026-06-06 | 70mm omni wheel + 3mm clamp hex coupling | 3 | 20.94 | 62.82 | Amazon | 113-8814706-5927456 | 2026-06-22 | 2026-07-02 | ordered | 3mm bore matches JGA12-N20B shaft
2026-06-06 | JGA12-N20B encoder gear motor 200RPM 12V | 4 | 7.20 | 28.80 | AliExpress | 8212329737371495 | 2026-06-16 | 2026-06-24 | ordered | verify bracket included in variant - check order details
2026-06-07 | B6 balance charger 80W with power supply | 1 | 38.98 | 38.98 | Amazon | 112-7693923-9876232 | 2026-06-09 | 2026-06-09 | received | includes XT60 JST T connectors and power supply
2026-06-07 | Zeee 3S LiPo 2200mAh 11.1V 35C T connector | 2 | 13.99 | 27.99 | Amazon | 112-7693923-9876232 | 2026-06-09 | 2026-06-09 | received | 2-pack - T connector matches charger cables
2026-06-07 | DC 12V to 5V USB-C buck converter 3A 15W | 1 | 7.99 | 7.99 | Amazon | 112-7693923-9876232 | 2026-06-09 | 2026-06-09 | received | powers Pi 5 from LiPo
2026-06-14 | M2 M3 540pcs bolt kit | 1 | 9.99 | 9.99 | Amazon |  | 2026-06-15 | 2026-06-15 | ordered | hex socket head cap screws assortment with hex wrench
2026-06-14 | Ninekong birch plywood 12x12 1/8 inch 12-pack | 1 | 25.55 | 25.55 | Amazon | 112-0041733-2565822 | 2026-06-15 | 2026-06-15 | ordered | 12 sheets 3mm birch for laser cutting and chassis prototyping

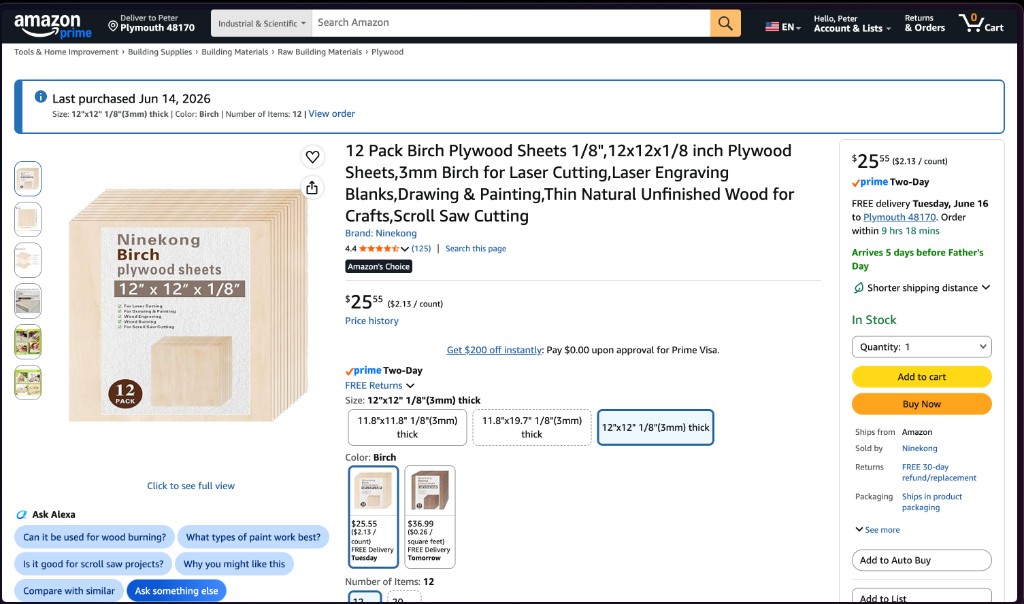
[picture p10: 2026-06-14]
hardware/bom/part-photos/materials/birch-plywood-12pack.png

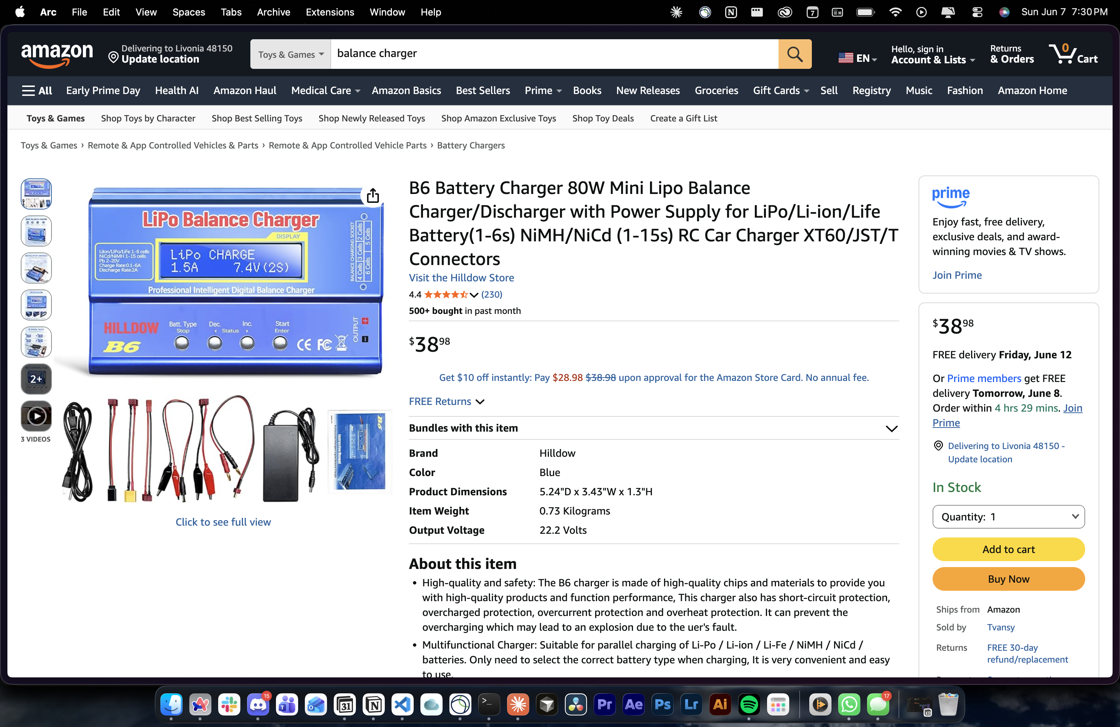
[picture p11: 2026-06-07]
hardware/bom/part-photos/power/balance-charger.png

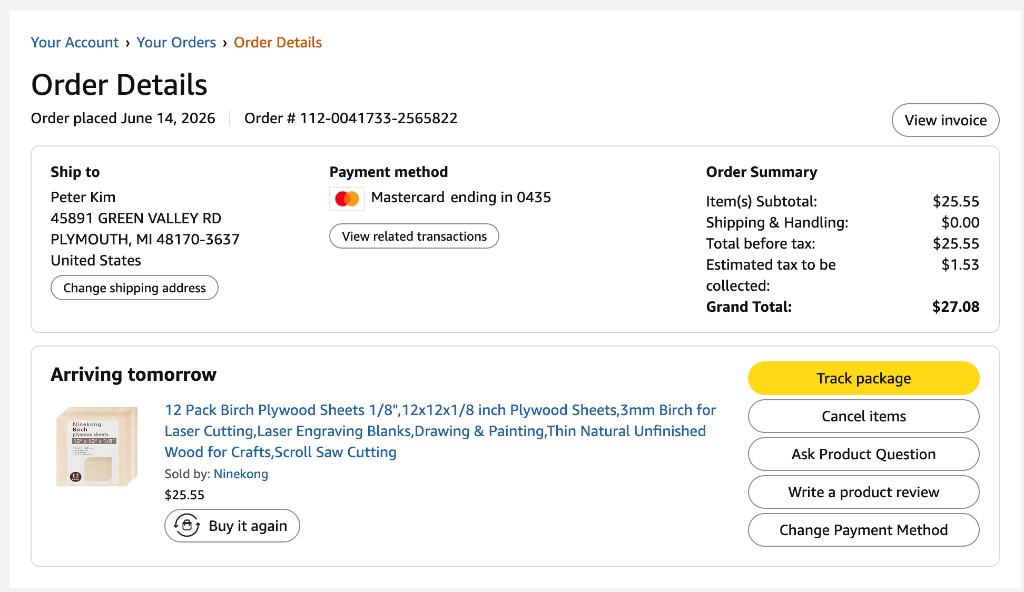
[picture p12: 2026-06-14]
hardware/bom/part-photos/orders/jun14-plywood-order.png

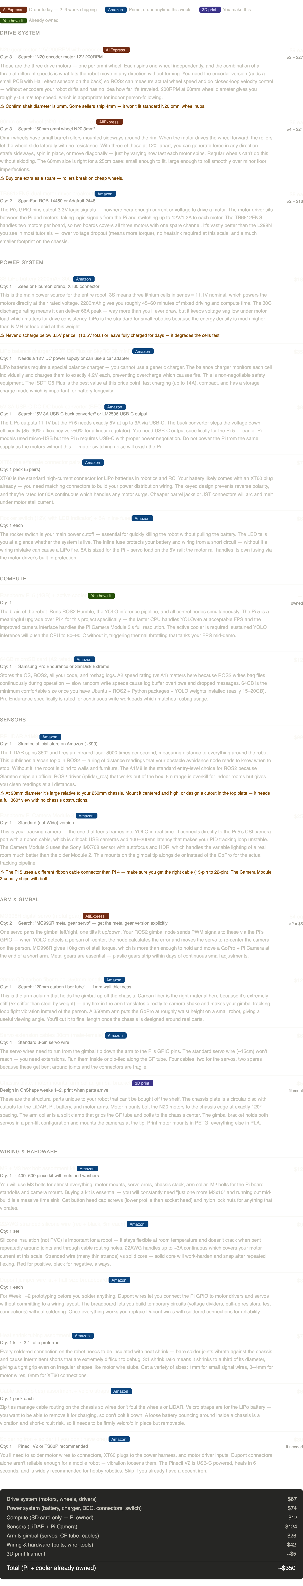
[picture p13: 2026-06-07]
hardware/bom/part-list.png

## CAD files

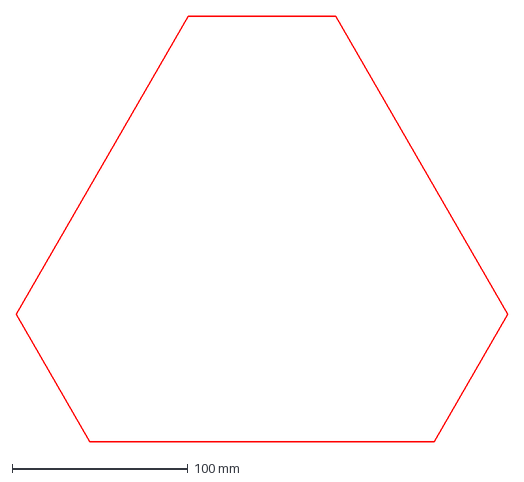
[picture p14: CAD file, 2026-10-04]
hardware/cad/chassis-plate.dxf
280.0 x 242.5 mm

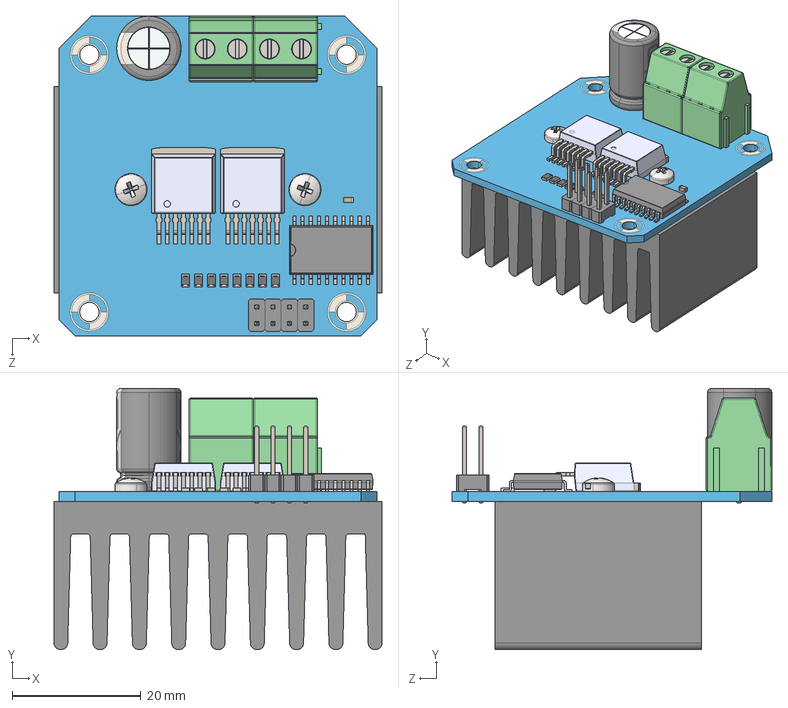
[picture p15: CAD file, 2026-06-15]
hardware/cad/refs/ibt-2/ibt-2.step
51.0 x 40.6 x 49.7 mm
IBT-2 (PCB)
IBT-2 (HS)
EC 10x16 P5 D0.6.step
TO263 (Plastic).STEP x 2
TO263 (Pin).STEP x 14
R GENERIC_R 0805 2012 x 8
SSOP (Plastic).STEP
SSOP (Pin).STEP x 20
C GENERIC_C 0603 1608 H(0.8)
TBLOCK (Generic)_TBLOCK 01x02 x 2
Header THV P2.54 (Plastic)_2 ROW x 4
Header THV P2.54 (Pin)_P2.54 (Long) x 8
pan cross head_am_B18.6.7M - M2.5 x 0.45 x 6 Type I Cross Recessed PHMS --6N x 2

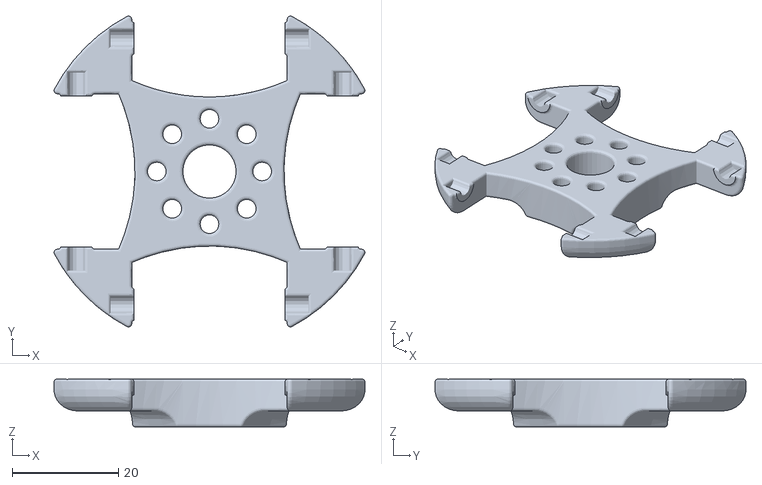
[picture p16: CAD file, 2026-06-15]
hardware/cad/refs/omni-wheel-70mm/omni-wheel-70mm-carrier.stl
58.4 x 58.4 x 9.00

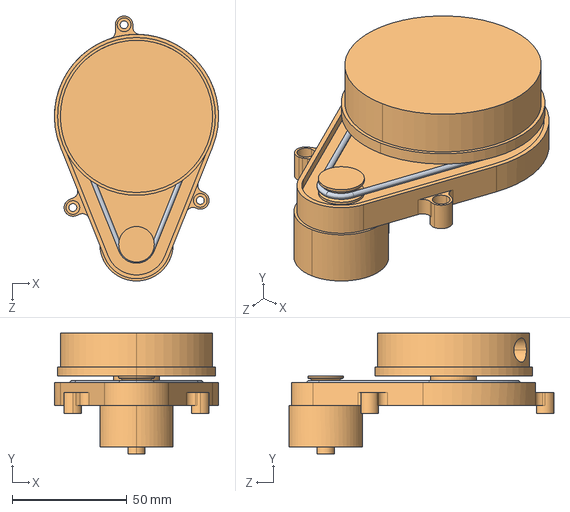
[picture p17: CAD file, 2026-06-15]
hardware/cad/refs/ydlidar-x4pro/ydlidar-x4pro.step
71.5 x 52.5 x 115.4 mm

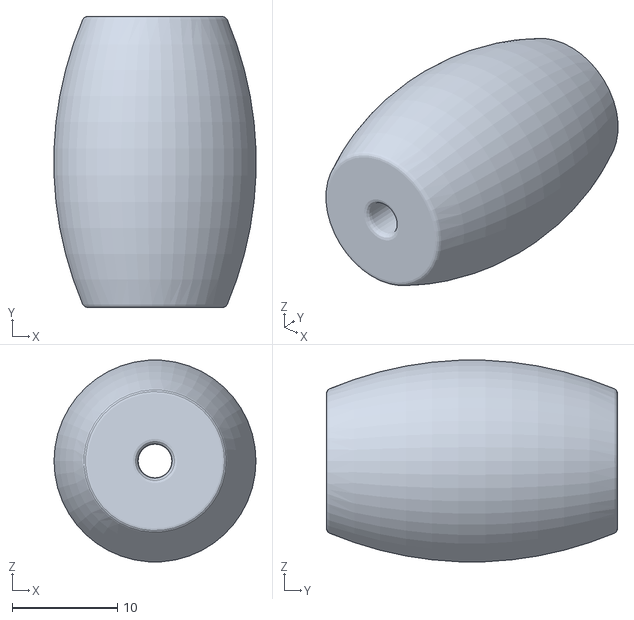
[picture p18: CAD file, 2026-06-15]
hardware/cad/refs/omni-wheel-70mm/omni-wheel-70mm-roller.stl
19.2 x 27.6 x 19.1

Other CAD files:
hardware/cad/chassis.dwg
hardware/cad/base.ipt
hardware/cad/chassis-plate.dwg
hardware/cad/chassis.ipt

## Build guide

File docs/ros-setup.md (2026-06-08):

# ros-setup
1. ssh pjk1m@fredfilmbot.local

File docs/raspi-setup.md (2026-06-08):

# raspi setup
1. flashed ubuntu 24.04 server on pi 5 with 32 gb micro sd
2. installed ros2 jazzy

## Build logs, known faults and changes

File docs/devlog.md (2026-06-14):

# devlog
jun 6th - sketched initial [design](docs/sketches/initial-design.jpg), set up repo, ordered [parts](hardware/bom/part-list.md)\
jun 7th - ordered more parts (here's [order csv](hardware/bom/orders.csv))\
jun 8th - [set up raspi](raspi-setup.md)\
jun 14th - ordered birch plywood 12-pack ([orders](hardware/bom/orders.csv), [product](https://www.amazon.com/dp/B0DLNJRP9L?th=1))

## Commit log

2026-06-06 testing cad inventor on caen
    [base.ipt]
2026-06-06 refactored + added drive photos
    [base.ipt]
2026-06-07 made 3 orders
    [orders.csv]
2026-06-07 Added inventory
    [inventory.csv]
2026-06-07 bought power supplies
    [orders.csv]
2026-06-14 Log received power parts in inventory.
    Mark charger, LiPo batteries, and buck converter as received and update intake photos.
    [inventory.csv, orders.csv]
2026-06-14 Add birch plywood order and update BOM records.
    Log Amazon order 112-0041733-2565822 across orders, inventory, part list, and devlog.
    [inventory.csv, orders.csv]
2026-06-15 Add chassis dimensions guide and YDLIDAR X4PRO specs.
    Document part sizes for CAD and identify the in-hand LiDAR with datasheet links.
    [inventory.csv]
2026-06-15 added cad ref models
    [ibt-2.step, omni-wheel-70mm-carrier.stl, omni-wheel-70mm-roller.stl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]
2026-06-15 designed chassis
    [chassis.ipt]
2026-07-20 Allow chassis DWG cut files in git.
    Ignore DWGs only under CAD refs so laser-cut exports can be committed.
2026-07-20 Add chassis plate DWG for laser cut
    [chassis.dwg]
2026-09-14 docs: add auto gimbal project schedule
    [auto-gimbal-schedule.csv]
2026-10-04 Update README, BOM, and add chassis CAD
    [chassis-plate.dwg, chassis-plate.dxf]
